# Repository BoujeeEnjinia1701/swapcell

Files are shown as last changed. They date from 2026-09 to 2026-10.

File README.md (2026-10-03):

# SwapCell

     

**Area:** Mobility and Logistics · **TRL:** 3 of 9 (proof of concept on paper) · **Value-engineering target:** about $700 USD · **Difficulty:** 4 of 5

Open-standard swappable battery pack and wall dock for e-bikes, scooters and cargo trikes, with a defined connector, CAN-based BMS protocol and state-of-health logging.

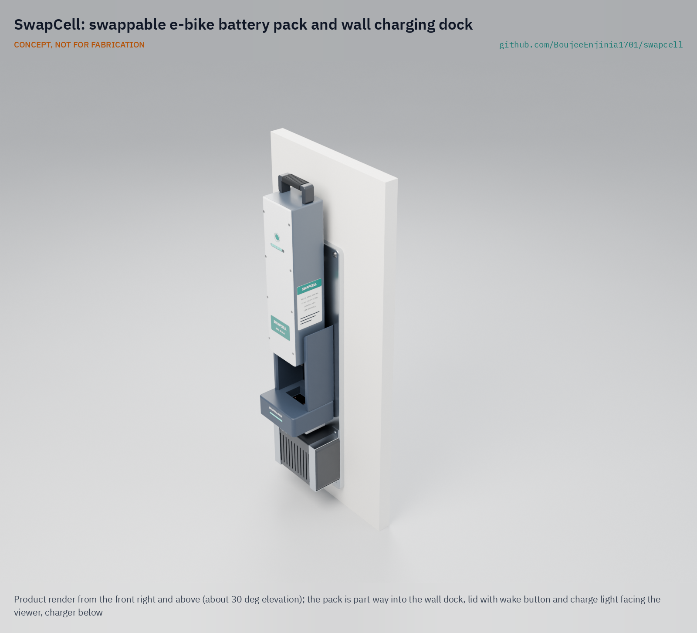
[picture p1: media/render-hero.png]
SwapCell: swappable e-bike battery pack and wall charging dock, product render


[Exploded render](media/render-exploded.png) · [Detail render](media/render-detail.png) · [Interactive 3D model](media/viewer.html) · [Concept blueprint (PDF)](media/concept-blueprint.pdf) · [Prototype build plan](docs/05-build-plan.md) · [Design decisions](docs/06-design-decisions.md) · [Review note](docs/REVIEW.md)

## Concept rationale

The cells inside almost every e-bike, scooter and cargo-trike battery are the same commodity 18650 or 21700 cells; what locks a pack to one brand is its housing, connector and data protocol. SwapCell therefore puts the effort into a published interface (envelope, pinout, coded interlock and CAN message set) rather than into a better cell. Once the interface is open, any fleet, workshop or small builder can make a pack or a receiver that works with everyone else's, and the pack's state-of-health log travels with it instead of living in a brand's cloud.

The reference build uses parts a garage workshop can source and assemble: commodity cells, an open-source BMS, a folded aluminium tray, a flame-retardant sheet lid and a certified off-the-shelf charger, so no custom mains electronics are needed. Keeping it open and buildable is what lets repair shops read and fix packs, and lets other open designs in this portfolio design around one battery instead of each inventing their own.

## Burning platform

Light electric vehicles are already the most electrified part of road transport: the IEA reports that about 8 % of the world's two- and three-wheelers were electric in 2023 and that electric models took 13 % of sales that year ([IEA, Global EV Outlook 2024](https://www.iea.org/reports/global-ev-outlook-2024/trends-in-other-light-duty-electric-vehicles)). In India, two-wheelers account for 70 to 80 % of all private vehicles ([NITI Aayog, draft Battery Swapping Policy, 2022](https://www.niti.gov.in/sites/default/files/2022-04/20220420_Battery_Swapping_Policy_Draft.pdf)), so how their batteries are charged, swapped and retired matters at national scale.

Closed, mismatched batteries are also a safety problem. In New York City, lithium-ion batteries caused 268 fires in 2023, killing 18 people and injuring 150 ([City of New York, 2024](https://www.nyc.gov/mayors-office/news/2024/07/mayor-adams-takes-new-actions-prevent-deadly-lithium-ion-battery-fires-promote-safe-e-bike)). A documented interface with a protected, dead-until-seated output and readable health data is one way to make safe, shared packs the easy choice.

## Where it could be used

### By industry

| Industry | Use |
| --- | --- |
| Last-mile delivery | Riders swap a flat pack for a charged one at a depot dock in seconds instead of waiting hours to charge |
| Bike and scooter sharing | One pack and dock family across mixed vehicle types, with state-of-health data to retire packs on evidence |
| Municipal, campus and industrial fleets | Shared packs for maintenance e-bikes, cargo trikes and site vehicles |
| Independent repair and refurbishment | Read a pack's log, find a weak cell group, repair it and return it to service |
| Agriculture and rural transport | Cargo trikes and e-bikes charged from a shared village dock or a small solar system |
| Off-grid energy | Retired or spare packs reused as storage in open power products such as PowerBox |

### By country or region

| Country or region | Why it matters there |
| --- | --- |
| India | About 880,000 electric two-wheelers and over 580,000 electric three-wheelers were sold in 2023 ([IEA](https://www.iea.org/reports/global-ev-outlook-2024/trends-in-other-light-duty-electric-vehicles)), and the government has proposed a battery swapping policy for these segments ([NITI Aayog](https://www.niti.gov.in/sites/default/files/2022-04/20220420_Battery_Swapping_Policy_Draft.pdf)) |
| China | Nearly 6 million electric two-wheelers were sold in 2023, the largest market in the world ([IEA](https://www.iea.org/reports/global-ev-outlook-2024/trends-in-other-light-duty-electric-vehicles)) |
| Kenya | Newly registered motorcycles, many used as boda-boda taxis, were estimated at 1.5 million in 2018 and could pass 5 million by 2030 ([UNEP](https://www.unep.org/news-and-stories/story/kenya-gets-breather-courtesy-electric-motorcycles)) |
| Viet Nam and Southeast Asia | Electric two-wheeler sales in Viet Nam were about 250,000 in 2023, and the electric share across ASEAN was only about 3 % ([IEA](https://www.iea.org/reports/global-ev-outlook-2024/trends-in-other-light-duty-electric-vehicles)), so shared packs could lower the entry cost |
| United States (New York City) | 268 lithium-ion battery fires and 18 deaths in 2023, and a city pilot of public battery charging for delivery workers ([City of New York](https://www.nyc.gov/mayors-office/news/2024/07/mayor-adams-takes-new-actions-prevent-deadly-lithium-ion-battery-fires-promote-safe-e-bike)) |

## What sparked the idea

The starting point was India's draft Battery Swapping Policy, published by NITI Aayog in April 2022 ([PDF](https://www.niti.gov.in/sites/default/files/2022-04/20220420_Battery_Swapping_Policy_Draft.pdf)). It asks for swappable batteries for two- and three-wheelers to be BMS-enabled, calls for standards for cables, connectors and repeated coupling tests, and favors open communication protocols so that batteries, vehicles and stations from different makers can work together. Those are the pieces of a common pack that no single brand has an incentive to publish. SwapCell takes that list literally and writes the interface down in the open: envelope, connector pinout with a coded interlock, CAN message set and health log, sized for e-bikes and cargo trikes.

## Problem

Every light electric vehicle brand uses its own battery, so fleets cannot share packs or chargers and batteries are scrapped early.

## Concept

Open-standard swappable battery pack and wall dock for e-bikes, scooters and cargo trikes, with a defined connector, CAN-based BMS protocol and state-of-health logging.

The core deliverable is the open **SwapCell interface v0.4**: envelope, blind-mate pinout with a coded interlock, CAN message set with a full bit layout, wake for hosts without CAN, a charge-while-discharging mode and a vehicle latch rating with its catch geometry published. Other portfolio designs build to it.

Full design precis: [docs/02-concept.md](docs/02-concept.md) · Sizing note: [docs/04-calcs/01-sizing.md](docs/04-calcs/01-sizing.md) · General arrangement: [cad/drawings/SWC-DWG-002.pdf](cad/drawings/SWC-DWG-002.pdf)

## Key components

- 26 x 21700 cells in 13S2P: 46.8 V, 10 Ah, about 468 Wh; pack about 3.0 kg
- Open-source BMS with CAN
- Folded aluminium tray with a flame-retardant UL 94 V-0 lid (polycarbonate sheet on the prototype)
- Blind-mate power and signal connector with a coded interlock
- Certified 5 A dock charger
- Latch pawl rated for vehicle class V1
- ESP32 dock controller

The priced bill of materials is in [bom/bom.csv](bom/bom.csv). Value-engineering target: USD 700. Estimated cost of the constructable design: USD 619 for one pack and one dock (USD 81 under the target).

## Building the prototype

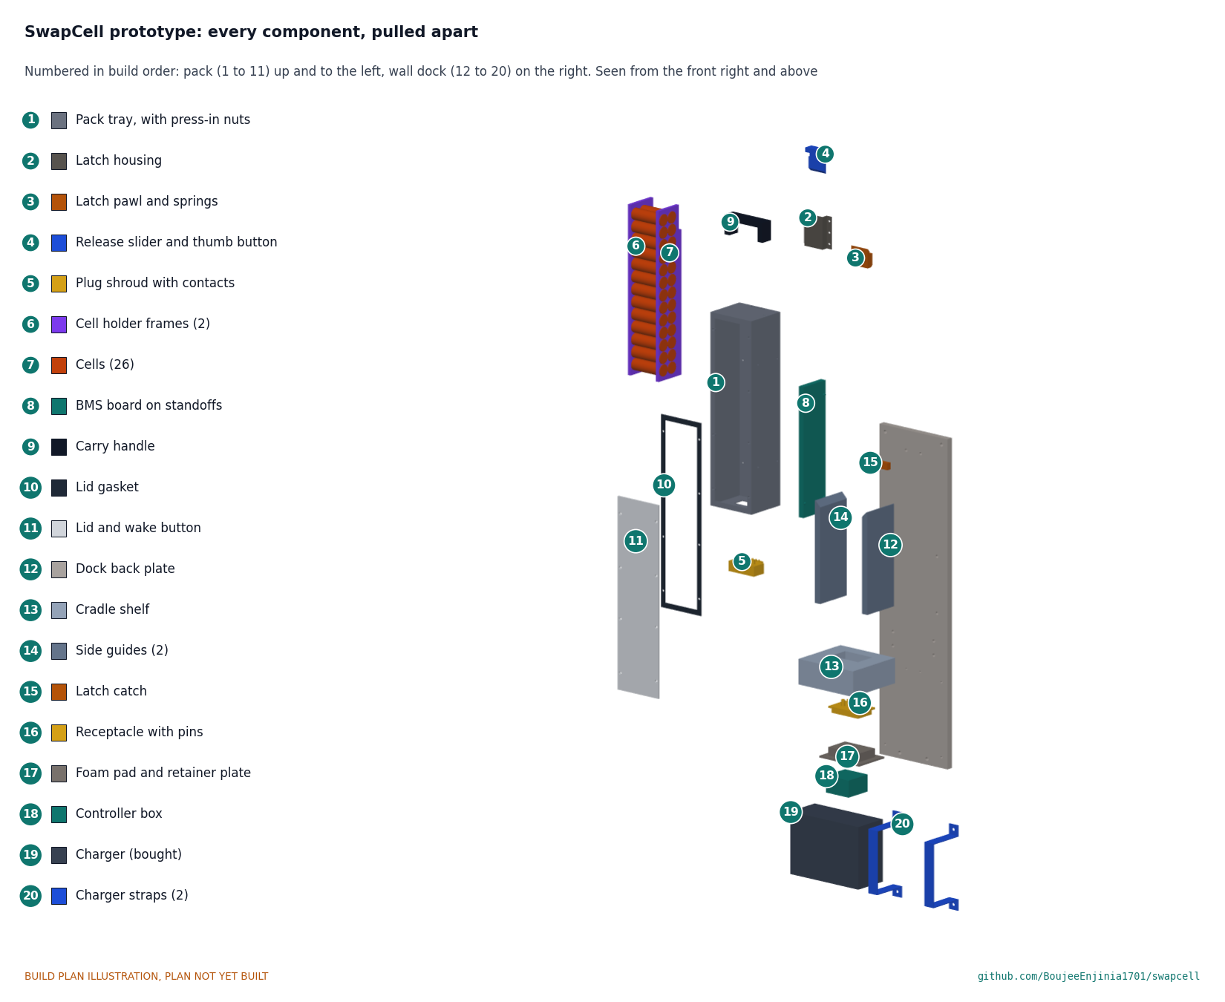
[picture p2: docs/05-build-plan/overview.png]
SwapCell prototype: every component pulled apart and numbered in build order


The [prototype build plan](docs/05-build-plan.md) (SWC-BLD-001) shows, in pictures, how to make each of the twenty components of one pack and one wall dock and put them together in seventeen steps; nothing has been built yet. The made parts are a folded aluminium tray, a steel latch with a thumb release, printed plug, receptacle, cell frames, handle, shelf and guides, and a 12 mm aluminium back plate; the cells, battery management board, contacts, charger and controller are bought. Writing the plan made the design buildable: the latch was redesigned so it actually holds the pack, the receptacle now floats, and every part has a fixing (SWC-DDR-003, open for Amish's review). Every picture is drawn from the model, which checks that each part touches what it should and clears what it should not; open questions are in the [design decisions register](docs/06-design-decisions.md).

## Safety

> Contains a 468 Wh lithium-ion battery pack at up to 54.6 V DC. Use a BMS with cell-level protection, fuse the pack, and charge on a non-combustible surface. Build and test packs only inside a fireproof enclosure, never unattended. This is a paper design at TRL 3; nothing here is certified.

## Repository layout

| Folder | Contents |
| --- | --- |
| `docs/` | Problem, concept, requirements, calculations and design decisions |
| `cad/src/` | build123d Python source, the source of truth for all geometry |
| `cad/step/`, `cad/stl/` | Exported models for FreeCAD, other CAD tools and printing |
| `cad/drawings/` | 2D sketches and dimensioned drawings |
| `bom/` | Bill of materials |
| `electronics/` | KiCad schematics and PCB layouts |
| `firmware/` | Microcontroller code |
| `media/` | Renders, perspectives and photos |
| `build-log/` | Dated prototyping notes |

## Documentation

Controlled documents follow the portfolio [documentation standard](.kit/STANDARDS.md). Each carries a document ID (SWC-PRC-001 for the precis), a version and a revision history. Branded PDFs are built with `python .kit/render.py` and attached to GitHub Releases when a document is tagged, for example `SWC-PRC-001/v1.0`.

## Credits

Designed by Amish Chadha. See [CONTRIBUTORS.md](CONTRIBUTORS.md) for roles. To cite this design, use [CITATION.cff](CITATION.cff) (GitHub shows it as "Cite this repository").

AI assistance (Claude) was used to accelerate concept renders, prototype documentation and first-pass sizing calculations. Design direction and all decisions are Amish Chadha's, recorded in this repository's decision records (`docs/decisions/`).

## Licenses

- **Hardware** (CAD, drawings, BOM, electronics): [CERN-OHL-S v2](LICENSE)
- **Software** (firmware, scripts, notebooks): [MIT](LICENSE-SOFTWARE)

A project of the [Design Molecule](https://designmolecule.com) lab.

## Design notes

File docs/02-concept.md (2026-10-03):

---
doc_id: SWC-PRC-001
title: SwapCell design precis
project: SwapCell
doc_type: Design precis
version: "0.7"
status: Draft
date: '2026-10-02'
author: Amish Chadha
license: CERN-OHL-S-2.0
revisions:
- version: "0.1"
  date: '2026-09-24'
  author: Amish Chadha
  change: Initial scaffold
- version: "0.2"
  date: '2026-09-24'
  author: Amish Chadha
  change: Populate to TRL 2 (architecture, interface definition, first-order numbers, safety, media)
- version: "0.3"
  date: '2026-09-25'
  author: Amish Chadha
  change: TRL 3. Issue SwapCell interface v0.3 (wake item W, charge-discharge item C, latch class V1 item V, full CAN bit layout); record Amish's decisions (SWC-DDR-001); numbers checked against SWC-CAL-001
- version: "0.4"
  date: '2026-09-25'
  author: Amish Chadha
  change: Recommendations accepted by Amish (DDR-002)
- version: "0.5"
  date: '2026-10-01'
  author: Amish Chadha
  change: Constructable design (SWC-DDR-003) latch, fixings and dock; mass and cost updated; budget treated as a value-engineering target
- version: "0.6"
  date: '2026-10-02'
  author: Amish Chadha
  change: "Issue SwapCell interface v0.4 (handle zone 84 x 43 mm, catch geometry, reserved LFP chemistry code and coding key); polycarbonate sheet lid for the prototype; partner, LFP and EnergyBus decisions of 2026-10-02"
- version: "0.7"
  date: '2026-10-02'
  author: Amish Chadha
  change: "Approved follow-ups carried out: lid line repriced for polycarbonate sheet (cost USD 619); board temperature sensor on the rear row of cells modelled; GA SWC-DWG-002 Rev P4 shows the handle zone and catch geometry"
---

# SwapCell design precis

SwapCell is a 48 V, 10 Ah lithium-ion pack of 26 cells in a 340 x 90 x 80 mm body that drops, connector first, into a wall dock or a vehicle mount, mates through a floating blind-mate connector, and talks to whatever it is plugged into over CAN. The pack carries its own state-of-health log, so any dock can read its history. The sizing note SWC-CAL-001 confirms that the 13S2P pack of 21700 cells gives about 468 Wh at about 3.0 kg, charges in about 2.3 h on a 5 A dock, and costs about USD 449 in prototype parts, with the dock adding about USD 170. The design was made constructable on 2026-10-01 (SWC-DDR-003, open for Amish's review), and the prototype build plan SWC-BLD-001 shows how it is made. Cycle life (R9) remains at risk. Cell temperature at 20 A (R3) is handled by the temperature derating rule Amish chose on 2026-09-25 (SWC-DDR-002).

The interface (envelope, pinout and message set) is the core deliverable of this precis. This version issues **SwapCell interface v0.4**, which widens the handle zone and publishes the latch catch geometry (Amish, 2026-10-02), on top of v0.3, which added three items Amish approved on 2026-09-25: a wake method for hosts without CAN or a wake supply (item W), a charge-while-discharging mode (item C) and a latch vibration rating for vehicles (item V). PowerBox, SunSpoke, StepGen, WaterWalker, CargoMule, FieldCell and other designs build to it.

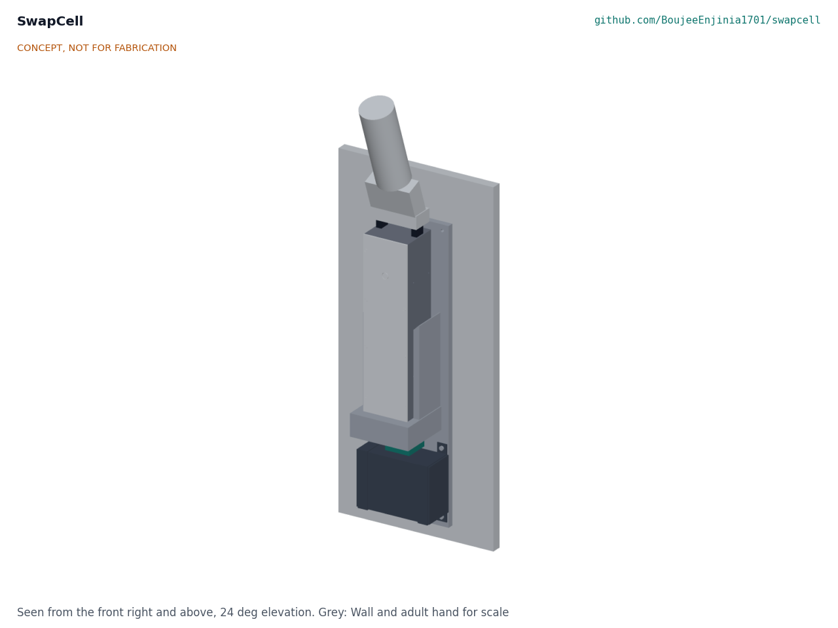
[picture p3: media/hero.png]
Hero render


*Figure 1. Pack seated in the wall dock, with a hand on the carry handle for scale. Rendered from the parametric model `cad/src/model.py`.*

## How it works

1. **Dock.** The pack hangs connector end down in a wall cradle. Side guides bring it within the connector's capture range, gravity seats it, and a spring-loaded pawl on the back face snaps out under a catch on the cradle.
2. **Mate and wake.** The blind-mate connector makes contact in sequence: ground first, then power and CAN, and a short interlock pin last. The receiver's 10 kΩ coding resistor in the INTERLOCK loop wakes a sleeping pack without any supply from the host. Until the pack has checked that loop, the output is dead.
3. **Handshake.** The dock controller (ESP32 with a CAN transceiver) sends a heartbeat. The pack answers with its identity, limits and state of health. If the pack reports no fault and a charge limit of at least 5 A, the dock switches its certified 54.6 V, 5 A charger onto the pack.
4. **Charge and log.** The BMS balances cells, limits charge by temperature and records each cycle. The dock copies new cycle records to its SD card and exports them as CSV.
5. **Swap.** The rider lifts the pack by the handle, releases the latch with the same hand, and slides it into the vehicle mount, which mirrors the dock cradle and closes an over-centre lever to hold the pack against vibration (latch class V1). The vehicle controller runs the same handshake, and the pack enables its output. A vehicle without CAN gets legacy discharge-only output at 15 A.
6. **Charge while in use.** A station host such as PowerBox, or a vehicle that recovers energy, requests the charge-discharge mode and may push current into the pack while drawing from it, within the limits the pack publishes.

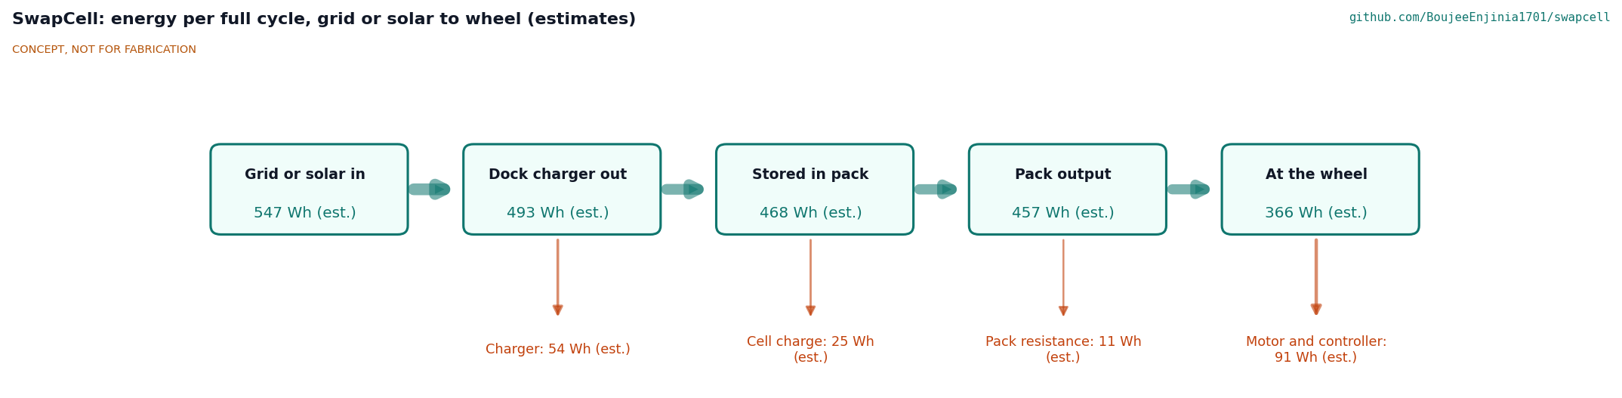
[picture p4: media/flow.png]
System and energy flow


*Figure 2. Energy per full charge and discharge, grid or solar to wheel. All values are estimates from SWC-CAL-001.*

## Main components

| # | Component | Proposed choice | Notes |
| --- | --- | --- | --- |
| 1 | Pack housing tray | Folded 1.5 mm 5052 aluminium, open front, flame-retardant liner, riveted latch doubler | Carries the latch and handle loads; spreads heat. Decided by Amish, 2026-09-25 |
| 2 | Cell block | 26 x 21700 cells, 13S2P, 5.0 Ah nominal (4.85 Ah minimum) and 3.6 V each, 25 A continuous rating | Cells in holders with fuse-wire links. Decided by Amish, 2026-09-25 |
| 3 | BMS board | Open-source 13S BMS with CAN, balancing, 30 A continuous FETs, pre-charge, flash log, 100 µA sleep with INTERLOCK wake | Stands beside the cells on its long edge |
| 4 | Pack lid | Flame-retardant polymer (UL 94 V-0 grade) on a flat gasket, eight countersunk screws into press-in nuts in the tray's front flanges, flush sealed wake button | Removable for repair |
| 5 | Blind-mate plug, pack side | 2 power contacts (40 A) plus 6 potted signal contacts in a keyed shroud | Fixed to the pack; custom keyed shroud with commercial contacts, decided 2026-09-25 (SWC-DDR-002) |
| 6 | Carry handle | Printed or moulded loop over the top end, 25 mm grip clearance, two screws from inside | Sized for a gloved hand |
| 7 | Latch pawl | Steel pawl sliding through the back wall in a riveted steel housing (the doubler), 6 mm proud, hooking 4 mm under the catch; a thumb button just behind the grip drives a ramped slider that pulls it in 5 mm; 1.72 kN proof load | Same catch geometry on dock and vehicle (SWC-DDR-003) |
| 8 | Wall dock cradle | 12 mm aluminium back plate, printed cradle shelf with connector pocket, printed side guides with lead-ins and a steel latch catch, each screwed from behind the plate | Wall-mounted at 0.8 to 1.2 m |
| 9 | Blind-mate receptacle, dock side | Mating half captured under the shelf pocket on a foam pad, floating ±3 mm and ±2°, 10 kΩ INTERLOCK coding resistor | Replaceable wear part |
| 10 | Dock charger | Certified 54.6 V, 5 A CC-CV lithium-ion charger, settable to 53.3 V for fleet mode | Off-the-shelf; no custom mains electronics. Decided by Amish, 2026-09-25 |
| 11 | Dock controller | ESP32 with CAN transceiver, charger relay, current sensor and SD card | Runs the handshake and exports logs |

Item 12 (fuses, pre-charge and wiring) is in the BOM but not modelled, apart from the battery board's temperature sensor on the rear row of cells; the label of item 14 is not modelled; items 13 (seals and fixings), 15 (latch housing and release), 16 (cell holder frames) and 17 (dock mounting parts) are modelled and shown in the build plan. Numbers match `bom/bom.csv` and Figure 4. The general arrangement is drawing SWC-DWG-002 (`cad/drawings/SWC-DWG-002.pdf`), generated from `cad/src/model.py`.

## Key numbers

All values come from SWC-CAL-001 (`docs/04-calcs/sizing.py`) and are paper estimates. Cell assumptions: 5.0 Ah nominal and 4.85 Ah minimum, 3.6 V nominal, 3.0 to 4.2 V, about 69 g, about 12 mΩ DC internal resistance, 25 A continuous, about $5.50 in small quantity.

| Quantity | Value | Basis | Requirement |
| --- | --- | --- | --- |
| Configuration | 13S2P, 26 cells | Decided by Amish, 2026-09-25 | |
| Voltage | 46.8 V nominal, 39.0 to 54.6 V | 13 x 3.6 V; 13 x 3.0 to 4.2 V | R1 met |
| Capacity and energy | 10.0 Ah and about 466 Wh at 0.2C; 9.7 Ah and 452 Wh at cell minimum | 2 x 5.0 Ah less sag | R2 **at risk** at cell minimum |
| Pack resistance | about 110 mΩ | 13 groups x 6 mΩ, plus 32 mΩ for links, fuse wires, FETs, shunt and connector | |
| Cell current | 10 A continuous, 17.5 A peak | 20 A and 35 A over 2 cells; rated 25 A | R3 electrically met |
| Cell hot spot, 20 A full discharge | about 51 °C in open air, 63 °C enclosed, 71 °C from 45 °C ambient | Lumped model, UA 1.17 W/K, τ 33 min | R3 met on paper with derating (SWC-DDR-002) |
| Heat at 10 A (typical e-bike) | about 11 W | I²R | |
| Voltage sag | about 2.2 V at 20 A, 3.9 V at 35 A | I x 110 mΩ | |
| Mass | about 3.03 kg (6.7 lb) | Cells 1.79 kg, tray 0.43, lid 0.11, interconnects 0.18, BMS 0.12, plug 0.06, handle and pawl 0.13, latch housing and release 0.11, seals, fixings and button 0.10 | R5 met |
| Body and overall size | 340 x 90 x 80 mm; 393 mm with handle and plug | Parametric model | R6 met |
| Energy density | about 154 Wh/kg, about 191 Wh/L | 468 Wh over 3.03 kg and 2.45 L | |
| Charge time at 5 A | about 2.3 h to full; 1.6 h to 80 %; 1.2 h for 20 to 80 % | CC to 85 % in 1.7 h, then about 0.6 h CV | R4 met |
| Dock input power | about 303 W in CC | 54.6 V x 5 A at 90 % | |
| Energy per cycle | about 547 Wh from grid or solar, about 457 Wh at the pack terminals | Figure 2 | |
| Range | about 38 to 57 km (e-bike), 18 to 30 km (loaded cargo trike) | 457 Wh at 12 to 8 Wh/km and 25 to 15 Wh/km | |
| Cell cost | about $143, $0.31/Wh | 26 x $5.50 | |
| Parts cost | about USD 449 per pack, USD 170 per dock, USD 619 total | `bom/bom.csv` | R16: USD 81 under the USD 700 value-engineering target |
| Cycle life | about 300 to 500 cycles to 80 % | Typical for the cell class; higher in 4.1 V fleet mode | R9 **at risk** |
| Sleep drain | about 0.72 % per month at 100 µA | Interface v0.3 item W | R13 met on paper |
| CAN bus load | about 1.8 % (one pack), 3.1 % (two packs) | 34.1 frames/s at 135 bits | R12 met on paper |

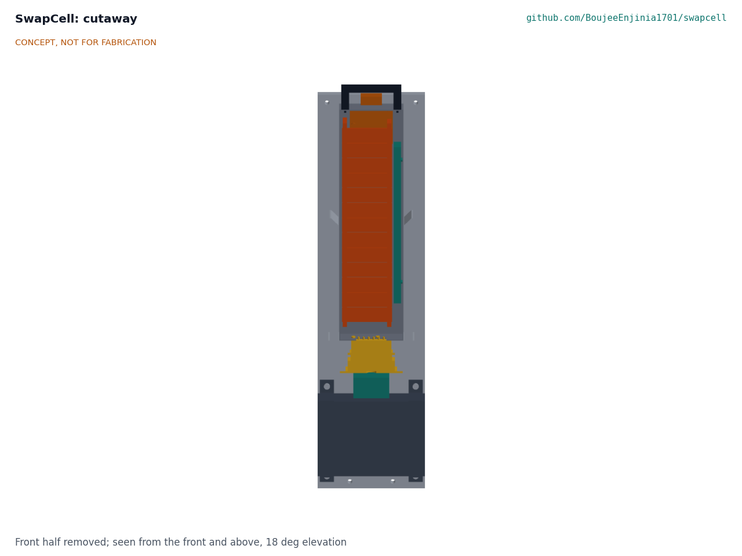
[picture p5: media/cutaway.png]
Cutaway


*Figure 3. Section through the docked pack: cells (2) with their axes across the width, BMS board (3) beside them, plug (5) in the dock receptacle (9).*

## Interface definition

This section is the **SwapCell interface, version 0.4** (draft, 2026-10-02). Amish approved v0.2 as written and the three v0.3 additions on 2026-09-25 (SWC-DDR-001), and the v0.4 changes of Table 1a on 2026-10-02 (SWC-DDR-003, A1 and A2; SWC-DEC-001). The specific values inside the additions (marked †) were engineering proposals; Amish confirmed them on 2026-09-25 (SWC-DDR-002). Other portfolio designs build to this section, cite it as "SwapCell interface v0.4", and flag any conflict to this repo rather than change it locally. Changes need Amish's approval.

*Table 1. Changes from v0.2.*

| Item | Change | Why | Requirement |
| --- | --- | --- | --- |
| W | Wake on a coded INTERLOCK loop (10 kΩ† to SGND in every receiver), plus a manual wake button; WAKE pin kept but optional | Battery-only and non-CAN hosts (PowerBox, legacy vehicles) have no wake supply | R13 |
| C | Requested mode 4, charge-discharge; host type 3, station; host charge limit in HOST_HEARTBEAT | PowerBox runs loads while charging from solar; vehicles may recover energy | R14 |
| V | Latch classes: D (gravity dock) and V1 (vehicle), with a proof load, preload and vibration profile | Vehicles shake; v0.2 had only a 3 g placeholder | R15 |
| L | Full CAN bit layout (Table 3) and interface version in PACK_STATUS | TRL 3 work listed in the TRL 2 review | R12 |

*Table 1a. Changes from v0.3 (2026-10-02).*

| Item | Change | Why | Requirement |
| --- | --- | --- | --- |
| H | Handle zone widened to 84 x 43 mm, from the zone's front edge to the back face | The thumb button sits behind the v0.3 zone; receivers must leave it clear | R6 |
| K | Catch geometry published: latching face 1 mm above the pawl, reach 8 mm from a plate 10 mm behind the pack, 4 mm engagement, 1 mm clear when retracted; pawl projection 6 mm, travel 5 mm | Every receiver must latch the same way | R15 |
| X | A chemistry code in the message set and a connector coding key are reserved for a 16S LFP variant, so an LFP pack can never take an NMC charge or the reverse; values and key geometry are assigned when an LFP variant is designed | Full charge differs (about 58.4 V for 16S LFP, 54.6 V for 13S NMC) | R12 |

### Mechanical envelope

| Feature | Value | Notes |
| --- | --- | --- |
| Body | 340 x 90 x 80 mm, +0 / -1.5 mm | Length along the insertion axis |
| Datum | Connector face (pack underside); insertion along the long axis, connector first | Same in dock and vehicle mount |
| Connector position | Centred across the 90 mm width, 8 mm toward the back face from the depth centre line | Keeps the plug clear of the lid seam |
| Guide faces | The two 340 x 80 mm side faces, 90 mm apart | Receiver guides with 1 mm clearance per side and a 10 mm lead-in |
| Latch | Pawl on the back face, 45 mm below the top end, 36 mm wide, 4 mm tooth, 6 mm projection, 5 mm travel; engages a catch on the receiver whose latching face is 1 mm above the pawl, reaching 8 mm from a plate 10 mm behind the pack, for 4 mm of engagement (v0.4) | Proof load 1.72 kN† along the insertion axis |
| Handle zone | Up to 35 mm above the top end, 84 x 43 mm footprint, from the zone's front edge to the back face (v0.4) | Receivers leave this zone clear, including the thumb button |
| Wake button | Flush in the lid (front) face, 12 mm, 70 mm below the top end | New in v0.3; inside the envelope |
| Orientation | Any; the latch, not gravity, retains the pack in a vehicle | Dock uses gravity to seat |
| Mass limit for receivers | 3.5 kg pack | R5 |
| Airflow | Vehicle receivers leave the back and lid faces open to air where possible | The full 20 A rating applies in an open-air mount; enclosed, the pack derates to about 18.6 A (R3) |

**Latch classes (item V).** *Class D* (gravity dock): the pack seats under its own weight; the latch only stops it being knocked out. *Class V1* (vehicle): the receiver and the pack latch together hold the pack with no latch release and no power-contact interruption of 1 ms or longer under the sinusoidal vibration profile of UN 38.3 test T3 (7 to 200 Hz, peak 8 g, three axes) and 25 g†, 11 ms half-sine shocks, three in each direction on each axis. The receiver preloads the pack against its end stop with at least 330 N† through an over-centre lever (ratio 6.6 or more, hand force 50 N or less), so the contacts do not chatter at 8 g; the lever has a detent so it cannot open under vibration. The pack latch withstands a static 1.72 kN proof load along the insertion axis without permanent set. Verification is by test at TRL 4, which is on hold.

### Connector pinout

Two power contacts and six signal contacts in a keyed shroud that only mates one way round. Mating order is set by contact length.

| Pin | Signal | Rating | Mates | Function |
| --- | --- | --- | --- | --- |
| P1 | PACK+ | 40 A continuous | 2nd | Pack positive, behind the BMS FETs; dead until enabled |
| P2 | PACK- | 40 A continuous | 1st | Pack negative |
| S1 | SGND | 1 A | 1st | Signal ground and CAN reference, joined to PACK- inside the pack |
| S2 | CAN_H | Signal | 2nd | CAN 2.0B, 250 kbit/s; 120 Ω termination in the host, not the pack |
| S3 | CAN_L | Signal | 2nd | As above |
| S4 | WAKE | 5 to 15 V, 10 mA | 2nd | Optional in v0.3. A host may drive it high to wake the BMS or hold it awake |
| S5 | AUX | 12 V, 1 A (reserved) | 2nd | Proposed low-power output for lights or a dock display; off by default |
| S6 | INTERLOCK | Signal, 3.3 V, 30 µA | 3rd (last) | **v0.3:** loops to SGND through a 10 kΩ† ±1 % coding resistor in every receiver. The pack accepts 8.0 to 12.5 kΩ (node 0.24 to 0.37 V); a short, an open loop or any other value keeps the output dead. It is also the wake source (item W) |

### Wake and sleep (item W)

In sleep the BMS draws 100 µA† or less and holds INTERLOCK at 3.3 V through 100 kΩ, with a comparator armed. The pack wakes on any of: INTERLOCK falling below 1.0 V, WAKE driven high, the manual button, or (optionally) CAN activity. Awake, it measures the INTERLOCK resistance. If the loop is valid, it goes to standby and waits for a heartbeat; if not, it sets a warning, keeps the output dead and sleeps again after 60 s, re-arming only when the node returns high, so a coin or water across the contacts cannot hold it awake. With no heartbeat, no current and a valid loop, the pack sleeps after 10 min unless a host holds WAKE high or sets the keep-awake flag. A host without CAN (legacy mode) therefore needs nothing but the coding resistor.

### CAN message set

CAN 2.0B controllers at 250 kbit/s, 11-bit identifiers. Each pack has a node number n from 0 to 7 (default 0) so a vehicle can carry two packs; identifiers below are base values plus n. All signals are little-endian unsigned integers unless marked signed. Current is positive out of the pack.

*Table 2. Messages.*

| ID (base) | Message | Direction | Rate |
| --- | --- | --- | --- |
| 0x100 | PACK_STATUS | Pack to host | 10 Hz |
| 0x110 | PACK_LIMITS | Pack to host | 10 Hz |
| 0x120 | CELL_SUMMARY | Pack to host | 1 Hz |
| 0x130 | TEMPERATURES | Pack to host | 1 Hz |
| 0x140 | FAULTS | Pack to host | On change and 1 Hz |
| 0x150 | STATE_OF_HEALTH | Pack to host | 0.1 Hz |
| 0x160 | IDENTITY | Pack to host | On request (remote frame or HOST_HEARTBEAT flag) |
| 0x180 | HOST_HEARTBEAT | Host to pack | 10 Hz |
| 0x190 | CHARGER_STATUS | Dock or station to pack | 1 Hz |
| 0x1F0 / 0x1F8 | LOG_REQUEST / LOG_DATA | Dock to pack / pack to dock | On request; segmented transfer in the style of ISO 15765-2 |

*Table 3. Bit layout (8 data bytes per frame; byte 0 first).*

| Message | Bytes | Signal | Scale and range |
| --- | --- | --- | --- |
| PACK_STATUS | 0 to 1 | Pack voltage | 10 mV, 0 to 655.35 V |
| | 2 to 3 | Pack current, signed | 100 mA, ±3,276.7 A |
| | 4 | State of charge | 0.5 %, 0 to 100 % |
| | 5 | State | 0 sleep, 1 standby, 2 discharge, 3 charge, 4 charge-discharge, 5 legacy discharge, 6 fault |
| | 6 | Flags | bit 0 INTERLOCK valid, 1 heartbeat valid, 2 discharge FET on, 3 charge FET on, 4 pre-charge active, 5 to 6 wake source (0 INTERLOCK, 1 WAKE, 2 button, 3 CAN), 7 fleet mode |
| | 7 | Counter and version | bits 0 to 3 rolling counter, bits 4 to 7 interface minor version (4 for v0.4) |
| PACK_LIMITS | 0 to 1 | Allowed discharge current | 0.1 A |
| | 2 to 3 | Allowed charge current | 0.1 A; 0 below 0 °C and above 45 °C cell temperature |
| | 4 to 5 | Maximum charge voltage | 10 mV (54.60 V standard, 53.30 V fleet) |
| | 6 to 7 | Minimum pack voltage | 10 mV |
| CELL_SUMMARY | 0 to 1, 2 | Minimum cell voltage, group index | 1 mV; 0 to 12 |
| | 3 to 4, 5 | Maximum cell voltage, group index | 1 mV; 0 to 12 |
| | 6 to 7 | Imbalance | 1 mV |
| TEMPERATURES | 0, 1 | Minimum and maximum cell temperature, signed | 1 °C |
| | 2, 3 | FET and connector temperature, signed | 1 °C |
| | 4, 5 | Sensor index of minimum and maximum | 0 to 255 |
| | 6 to 7 | Reserved | 0 |
| FAULTS | 0 to 3 | Fault bits | 0 cell overvoltage, 1 cell undervoltage, 2 discharge overcurrent, 3 charge overcurrent, 4 short circuit, 5 over-temperature, 6 under-temperature charge, 7 INTERLOCK invalid, 8 heartbeat lost, 9 pre-charge failed, 10 FET failure, 11 cell imbalance, 12 isolation or water ingress, 13 to 31 reserved |
| | 4 to 5 | Warning bits | Same order as faults, early warning thresholds |
| | 6 | Seconds until disconnect | 1 s; 255 = none pending |
| | 7 | Rolling counter | 0 to 255 |
| STATE_OF_HEALTH | 0 | SoH | 0.5 % |
| | 1 to 2 | Full-charge capacity | 10 mAh |
| | 3 to 4 | Cycle count | 1 |
| | 5 to 6 | Lifetime throughput | 10 Ah |
| | 7 | Resistance estimate | 1 mΩ, 0 to 255 |
| IDENTITY | 0 | Page | 0 to 3 |
| | 1 to 7 | Page 0: interface major and minor, chemistry code, series count, parallel count, rated capacity (0.1 Ah, 2 bytes); pages 1 and 2: serial number (14 ASCII bytes); page 3: firmware version | |
| HOST_HEARTBEAT | 0 | Host type | 0 vehicle, 1 dock, 2 tester, 3 station (new in v0.3) |
| | 1 | Requested mode | 0 sleep, 1 standby, 2 discharge, 3 charge, 4 charge-discharge (new in v0.3) |
| | 2 to 3 | Host discharge current limit | 0.1 A |
| | 4 to 5 | Host charge current limit | 0.1 A (new in v0.3) |
| | 6 | Flags | bit 0 fleet mode, 1 keep awake, 2 request IDENTITY, 3 to 7 reserved |
| | 7 | Rolling counter | 0 to 255 |
| CHARGER_STATUS | 0 to 1, 2 to 3 | Charger voltage and current capability | 10 mV, 0.1 A |
| | 4 to 5, 6 to 7 | Measured output voltage and current | 10 mV, 0.1 A |

### Behavior rules

- **Enable.** The pack enables any output only with a valid INTERLOCK loop. Discharge needs a heartbeat requesting mode 2 or 4; charge needs a heartbeat from a dock, station or vehicle requesting mode 3 or 4. A heartbeat is valid while its counter advances at least every 300 ms.
- **Legacy mode (decided).** If INTERLOCK is valid and no heartbeat arrives within 2 s, the pack enables discharge only, limited to 15 A, and never charges or enters mode 4.
- **Charge-discharge mode (item C).** In mode 4 both FETs are on and current may flow either way. The host keeps net charge current at or below the lower of its own charge limit and the pack's allowed charge current, and the pack terminal voltage at or below the maximum charge voltage. The pack enforces its limits: on a charge-side fault (charge overcurrent, a cell near overvoltage, or cell temperature below 0 °C or above 45 °C) it sets allowed charge current to zero, warns, and after 1 s opens only the charge FET, so discharge continues through that FET's body diode and the load stays powered. Mode changes between 2, 3 and 4 never open the output.
- **Temperature derating (R3, decided 2026-09-25).** PACK_LIMITS allows the full 20 A continuous discharge while the hottest cell is at or below 50 °C, then lowers the allowed discharge current linearly to 5 A at 60 °C. The 35 A, 10 s peak is allowed only below 50 °C. Hosts must follow PACK_LIMITS; a legacy host is already held to 15 A and gets the same ramp. The pack sustains about 18.6 A in an enclosed mount from 25 °C and about 14 A in open air from 45 °C (SWC-CAL-001 v0.2).
- **Warn, then derate.** For a non-fatal fault the pack first warns and ramps its current limit down over about 5 s, so a rider is not left without power mid-junction. It opens immediately only for short circuit, cell overvoltage or over-temperature beyond the hard limit.
- **Removal.** When INTERLOCK opens (it breaks first on removal), the pack opens its output within 1 ms, before the power contacts separate.

**State-of-health log.** One 32-byte record per charge or discharge event: dock timestamp, Ah in and out, minimum and maximum temperature, peak current, minimum cell voltage, capacity and resistance estimates. 2,000 records need 64,000 bytes, which fits in the BMS microcontroller flash or a small SPI flash and transfers in about 10 s (R12).

**EnergyBus gateway.** Decided: an open SwapCell profile now, with a gateway study. The study is not complete. A gateway (an ESP32 translating between the two message sets) looks feasible in principle, since both carry voltage, current, limits and state, but a message-by-message mapping needs the CiA 454 specification, which is distributed through a membership organization and was not read for this version.

## Key design choices

All of these were decided by Amish on 2026-09-25 (go with recommendation), SWC-DDR-001, unless marked otherwise.

- **13S2P of 5 Ah 21700 cells.** Meets 10 Ah with 26 cells and 52 welds. A 13S4P "double" pack (about 900 Wh, about 5 kg) is a later variant in a longer envelope.
- **Aluminium tray with a flame-retardant lid (3 mm UL 94 V-0 polycarbonate sheet for the prototype, decided 2026-10-02; a printed V-0 lid remains allowed).** Metal spreads heat, resists a cell fire longer than a printed shell and carries the 1.72 kN latch proof load through a riveted doubler.
- **Floating blind-mate connector with a dead pack output and a coded interlock.** Sequenced contacts and a last-mate, resistor-coded interlock keep the output off until the pack is seated in a real receiver, avoid arcing on insertion and let a receiver wake the pack.
- **Own open message set, with an EnergyBus gateway study.** Short, published and easy to implement on an ESP32 or a hobby controller.
- **Legacy mode for vehicles without CAN.** Discharge only, fixed at 15 A.
- **The log lives in the pack.** Any dock, anywhere, can read a pack's history without a shared server.
- **Certified charger, switched by the dock.** The dock builds no mains electronics; charge current is fixed at 5 A.
- **Fleet charge mode.** The dock may set 4.1 V per cell (53.3 V) for longer life at about 10 % less energy.
- **Interface governance.** This section is the versioned interface; Amish approves changes.
- **Solar DC dock variant.** A second dock with a 48 V DC input (via PowerBox) follows the mains dock; not designed at TRL 3.
- **Connector family (decided 2026-09-25, SWC-DDR-002).** A custom printed keyed shroud around commercial high-current socket contacts and potted spring signal contacts, rather than a commercial blind-mate connector, because it keeps the published geometry independent of one vendor; the contacts are bought and replaceable. The specific contact parts are chosen at supplier selection. R8 and R10 depend on them and are verified at TRL 4, which is on hold.
- **R3 thermal rating (decided 2026-09-25, SWC-DDR-002).** Keep 20 A continuous at 25 °C with the temperature derating rule above, rather than labelling the pack 15 A.
- **Values inside items W, C and V (confirmed 2026-09-25, SWC-DDR-002).** 10 kΩ coded INTERLOCK, 100 µA sleep limit, 25 g shock, 330 N receiver preload, and the charge-FET fallback on a charge-side fault.

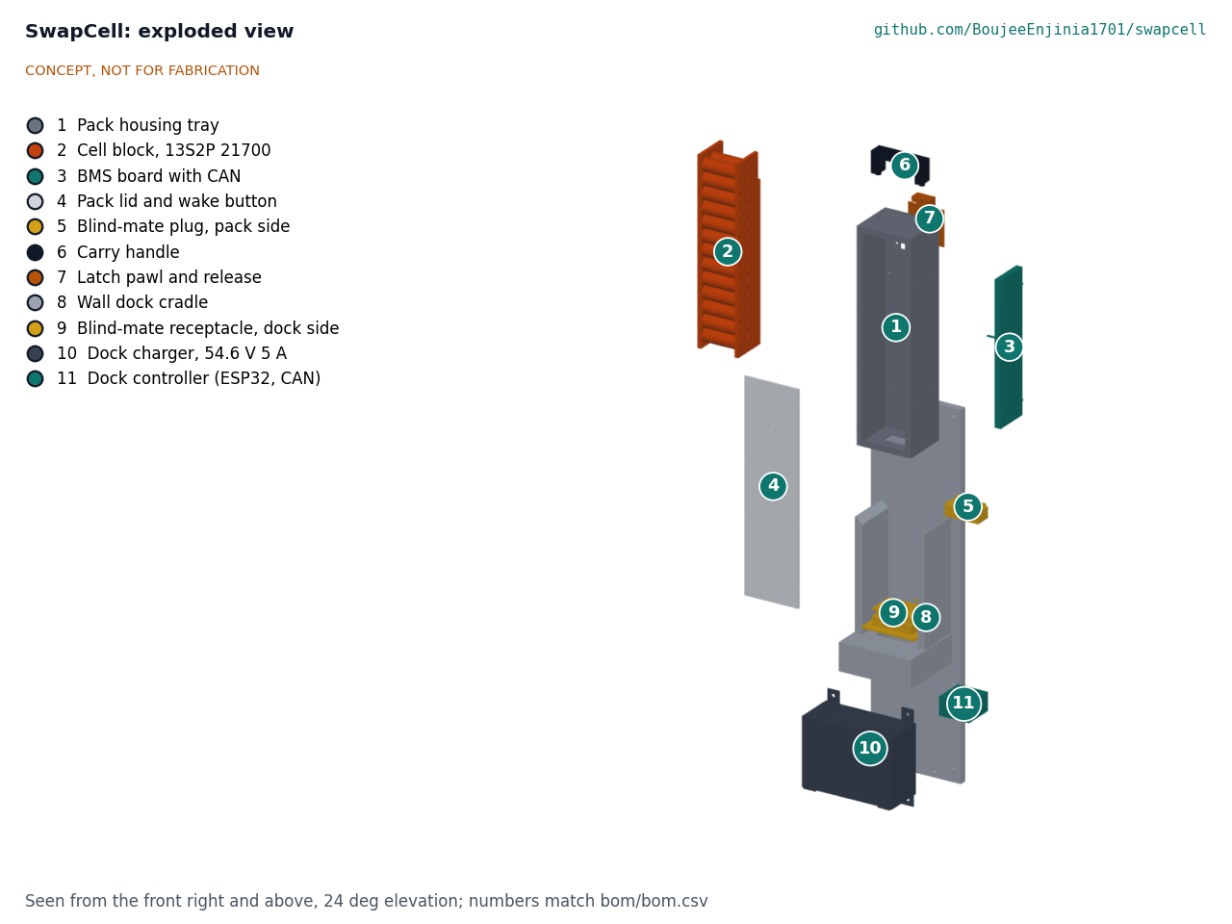
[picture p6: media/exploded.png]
Exploded view


*Figure 4. Exploded view with callouts numbered as in the components table and `bom/bom.csv`.*

## Safety

> **Safety:** SwapCell is a 468 Wh lithium-ion pack. A cell in thermal runaway vents flammable, toxic gas and can ignite its neighbours; a pack fire is hard to extinguish and can re-ignite hours later. Treat every pack as a fire hazard at all stages.

- **Thermal runaway.** Use new cells from a reputable distributor, with matched capacity and resistance. Space cells in holders (about 1 mm gaps) and consider a mica or intumescent barrier between groups; line the tray with a flame-retardant sheet; give the housing a vent path that directs gas away from the handle and the user. Propagation resistance was not analyzed at TRL 3 and can only be shown by test, which is TRL 4 work and on hold.
- **Cell-level fusing.** Each cell connects to its bus through a fuse wire or fusible link sized to carry 17.5 A peak without damage but to open on the fault current of an internally shorted neighbour. A 40 A main fuse sits in series with PACK+.
- **BMS protections (R11).** Cell overvoltage and undervoltage, charge and discharge overcurrent, short-circuit trip within 500 µs, over-temperature, no charging below 0 °C, pre-charge of the host's input capacitors, and an output that stays off until the interlock closes. Exposed pack contacts are at up to 54.6 V DC and can deliver hundreds of amperes into a short, so the dead-output rule is a safety requirement, not a convenience.
- **Coded interlock (v0.3).** A bare link or a coin across INTERLOCK and SGND reads as a short and never enables the output, even in legacy mode. Receivers must fit the 10 kΩ coding resistor; a receiver that shorts the loop simply does not work, which fails safe.
- **Charge-discharge mode (v0.3).** A host that pushes current into a pack is a charger. The pack refuses charge below 0 °C and above 45 °C and opens only its charge FET on a charge-side fault, so the load stays powered and the cells are protected. Hosts must still limit their own charge current and voltage.
- **Pack retention in vehicles (v0.3).** A pack that leaves its mount at speed is a 3 kg projectile with live contacts. Vehicle receivers must meet latch class V1, with an over-centre lever that cannot open under vibration.
- **Loss of power while riding.** A pack that cuts out suddenly can cause a fall. The warn-then-derate rule in the message set applies to every fault except the hard ones.
- **Dock location.** Mount docks on a non-combustible wall, away from exits and escape routes, with a smoke alarm nearby. Do not charge packs that have been dropped, crushed or wetted until they have been inspected.
- **Transport rules.** At about 468 Wh the pack is well above 100 Wh, so it ships as Class 9 dangerous goods (UN 3480 alone, UN 3481 in or with equipment), needs a UN 38.3 test summary before commercial shipping, cannot travel in passenger air baggage, and by air generally has to ship at 30 % state of charge or less. Moving prototype packs by road between workshops still needs terminal protection and a rigid, non-conductive container.
- **Building and testing.** Build, charge and test prototype packs only inside a fireproof enclosure (a steel cabinet or a purpose-made battery containment box) on a non-combustible surface, with a Class D or lithium-rated extinguisher and a sand bucket at hand, and never unattended. Use insulated tools, cover exposed bus bars, and build the pack one series group at a time with the BMS disconnected until wiring is checked.
- **Standards.** EN 50604-1 and UL 2271 (light-vehicle batteries), UL 2849 (e-bike electrical systems) and IEC 62133-2 are future compliance targets. Nothing here is certified.

## Open questions

Every open item, with options and recommendations, is tracked in the design decisions register SWC-DEC-001 ([06-design-decisions.md](06-design-decisions.md)); the list below is a summary.

Items that remain open after SWC-DDR-002. None of them is TRL 4 work to be started now; TRL 4 is on hold by Amish's instruction.

- **Cell model (R9).** Which 5 Ah 21700 cell balances cycle life against current rating needs datasheet review against named cells; R9 stays at risk until then.
- **LFP variant.** A 16S LFP pack (about 51 V nominal, up to 58.4 V) would be safer and longer lived but heavier. PACK_LIMITS already allows a different voltage window. Decided 2026-10-02: not added now; a chemistry code and a coding key are reserved in interface v0.4 so an LFP pack can never take an NMC charge or the reverse.
- **EnergyBus mapping.** Deferred (2026-10-02): the native SwapCell profile stays the reference; CiA 454 is read only when a partner needs EnergyBus.
- **First co-design partner.** Left open under the portfolio rule, but an urban cargo-bike or e-bike delivery fleet is approached first, with a repair workshop second (decided 2026-10-02). Nothing is agreed.
- **Build budget for a second pack.** Decided 2026-09-25 to settle it before any build (about USD 1,068 for two packs and one dock with the constructable design); on hold with TRL 4.

Concept media: [blueprint sheet](../media/concept-blueprint.pdf), [interactive 3D model](../media/viewer.html).

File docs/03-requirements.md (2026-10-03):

---
doc_id: SWC-REQ-001
title: SwapCell requirements
project: SwapCell
doc_type: Requirements
version: "0.7"
status: Draft
date: '2026-10-02'
author: Amish Chadha
license: CERN-OHL-S-2.0
revisions:
- version: "0.1"
  date: '2026-09-24'
  author: Amish Chadha
  change: Initial scaffold
- version: "0.2"
  date: '2026-09-24'
  author: Amish Chadha
  change: First measurable requirements for TRL 2 (electrical, mechanical, interface, protection)
- version: "0.3"
  date: '2026-09-25'
  author: Amish Chadha
  change: TRL 3. Record Amish's 2026-09-25 decisions (SWC-DDR-001); add R13 to R15 for interface v0.3 (wake, charge-discharge mode, latch class V1) and R16 budget scope; status from SWC-CAL-001
- version: "0.4"
  date: '2026-09-25'
  author: Amish Chadha
  change: Recommendations accepted by Amish (DDR-002)
- version: "0.5"
  date: '2026-10-01'
  author: Amish Chadha
  change: Constructable design (SWC-DDR-003) mass and cost; budget treated as a value-engineering target
- version: "0.6"
  date: '2026-10-02'
  author: Amish Chadha
  change: "Interface v0.4 noted (decisions of 2026-10-02); no requirement target or status changed"
- version: "0.7"
  date: '2026-10-02'
  author: Amish Chadha
  change: "R16 figures updated for the polycarbonate sheet lid (USD 619, USD 81 under the target); no requirement status changed"
---

# SwapCell requirements

These are the requirements for the pack, the dock and the SwapCell interface between them (v0.4 since 2026-10-02: handle zone 84 x 43 mm, catch geometry published, LFP chemistry code and coding key reserved; no requirement target changed). Amish accepted the TRL 2 recommendations on 2026-09-25 (SWC-DDR-001), including three interface additions, now R13 to R15. Requirements R6, R10 and R12 to R15 define the open interface that other portfolio designs depend on, so changes to them need Amish's approval. On 2026-09-25 Amish also accepted the remaining recommendations (SWC-DDR-002): R3 is restated around temperature derating, and the values inside R13 and R15 are confirmed. The status column comes from SWC-CAL-001 v0.2; no requirement is shown to be not met, and two are at risk.

| ID | Requirement | Target | Verification | Status (SWC-CAL-001) |
| --- | --- | --- | --- | --- |
| R1 | Nominal voltage in the 48 V light-vehicle class | 46.8 V nominal; operating window 39.0 to 54.6 V (3.0 to 4.2 V per cell) | Cell configuration calculation; datasheet | Met |
| R2 | Usable capacity and energy | 10 Ah or more and 450 Wh or more at 0.2C, 25 °C | Calculation from cell datasheet; later capacity test. Applies to the standard 4.2 V charge; fleet mode (4.1 V) gives about 419 Wh by design | At risk: 9.7 Ah at the cell datasheet minimum |
| R3 | Discharge current, continuous and peak, with temperature derating | 20 A continuous for a full discharge with cells below 60 °C from 25 °C ambient in an open-air mount (back and lid faces open); 35 A peak for 10 s. In any other mount or ambient, PACK_LIMITS derates the allowed discharge current (full to 50 °C cell temperature, linear to 5 A at 60 °C) so cells stay below 60 °C | Thermal and cell-current calculation; later load test | Met on paper: 51 °C in open air (56 °C with higher resistance); derates to about 18.6 A enclosed and 14 A from 45 °C |
| R4 | Charge time at the standard dock | 3 h or less from empty to full at 5 A; 80 % in 2 h or less | CC-CV charge calculation | Met |
| R5 | Mass for one-hand carry and swap | 3.5 kg or less (7.7 lb) including handle and connector | Mass budget; later weighing | Met: 3.03 kg (SWC-DDR-003) |
| R6 | Mechanical envelope (interface) | Body 340 x 90 x 80 mm, +0 / -1.5 mm; overall length with handle and plug 400 mm or less | Massing model, then drawing sheet | Met: 393 mm overall |
| R7 | Swap time and effort | Pack out of a dock or vehicle and a charged pack seated and latched in 10 s or less, one hand, no tools; insertion force 50 N or less | Design review; later timed trial | Not verifiable at TRL 3 |
| R8 | Ingress protection | Pack IP65, including the unmated connector face; dock IP54 for sheltered outdoor mounting | Design review of seals and contacts | Not verifiable at TRL 3 |
| R9 | Cycle life and state-of-health tracking | 500 cycles or more to 80 % of rated capacity at 0.5C charge and discharge, 25 °C; SoH estimate within ±5 % | Cell datasheet review; later cycling data. The 4.1 V fleet charge mode (decided) is the main mitigation | At risk |
| R10 | Blind-mate connector (interface) | 5,000 mating cycles or more; self-aligns over ±3 mm lateral and ±2° angular misalignment; 40 A continuous per power contact; contact sequence PACK- first, INTERLOCK last | Connector datasheet; design review. Family decided: custom keyed shroud with commercial contacts (SWC-DDR-002) | Not verifiable at TRL 3 |
| R11 | Protections | Cell overvoltage and undervoltage, charge and discharge overcurrent, short-circuit trip within 500 µs, over-temperature, charge lockout below 0 °C, cell-level fusing, pre-charge, output dead when unmated | BMS specification review; later fault injection | Not verifiable at TRL 3 |
| R12 | Data interface and logging (interface) | CAN 2.0B at 250 kbit/s with a published message set; pack stores 2,000 or more cycle records; any conforming dock reads and exports them as CSV without a cloud account; bit layout as published in SWC-PRC-001 v0.3 | Message set review, bus-load calculation; later bench decode | Met on paper |
| R13 | Wake for hosts without CAN or a wake supply (interface v0.3 item W) | Pack wakes from sleep when a receiver closes INTERLOCK through a 10 kΩ coding resistor, drawing no supply from the host; also wakes on WAKE (5 to 15 V) or its manual button; rejects a shorted or open loop; sleep drain 1 % of capacity per month or less; legacy discharge-only mode at 15 A for hosts without CAN | Calculation; later bench check | Met on paper |
| R14 | Charge-while-discharging mode (interface v0.3 item C) | Dock, station and vehicle hosts may request mode 4 (charge-discharge); pack allows net current between the allowed charge and allowed discharge limits without interrupting its output, and on a charge-side fault stops charge only and keeps discharge | Message set review; calculation; later bench check | Met on paper |
| R15 | Latch vibration rating for vehicles (interface v0.3 item V) | Class V1 vehicle receivers and the pack latch: no latch release and no power-contact interruption of 1 ms or longer under the UN 38.3 test T3 sine profile (7 to 200 Hz, peak 8 g) in three axes and 25 g, 11 ms half-sine shocks; latch proof load 1.72 kN along the insertion axis; receiver preload 330 N or more with 50 N or less hand force. Class D (gravity docks) needs no rating | Calculation; later vibration test (TRL 4, on hold) | Not verifiable at TRL 3 |
| R16 | Prototype cost scope | Parts for one pack and one wall dock at the USD 700 value-engineering target or under (`budget_usd` in `project.yaml`, a hypothetical control target, not a limit). A SwapCell pack is priced once, here, and excluded from each dependent kit budget | Priced BOM | Under the target: USD 619, USD 81 under |

## Assumptions

- A 48 V class pack is 13 lithium-ion cells in series. The 3.0 V per cell lower limit is conservative for most NMC and NCA cells; the BMS enforces it regardless of the vehicle controller cutoff.
- 20 A continuous (about 940 W) covers a 750 W cargo-trike motor with margin. E-bikes at 250 to 500 W draw 5 to 11 A.
- A fleet vehicle swaps once or twice a day. Over five years that is about 3,650 mating cycles, so R10 at 5,000 cycles has about 37 % margin (SWC-CAL-001). Dock-side contacts see more cycles than pack-side ones and should be replaceable.
- R5 and R7 assume an adult lifting from a wall dock at 0.8 to 1.2 m height. A lower mounting height would need a review of R5.
- R9 depends on the cell chosen. High-energy 21700 cells often quote fewer cycles than high-power cells; see SWC-PRC-001.
- R13 to R15 were approved by Amish on 2026-09-25 as interface v0.3 additions. The specific values (10 kΩ coding, 100 µA sleep target, 25 g shock, 330 N preload) were engineering proposals inside those additions; Amish confirmed them on 2026-09-25 (SWC-DDR-002).
- R15 uses the UN 38.3 test T3 vibration profile because every pack must pass it for transport anyway; the 25 g shock is a proposed curb-strike level for rigid cargo vehicles.
- R16: the USD 700 value-engineering target covers the parts for one pack and one dock. A second pack for a real swap demonstration (about USD 449 more, about USD 1,068 in total with the constructable design) is a build budget, to be set before any build as Amish decided on 2026-09-25 (SWC-DDR-002); it is on hold with TRL 4.

> **Safety:** The pack is a 468 Wh lithium-ion battery at up to 54.6 V DC that can deliver about 500 A into a short. R11, R13 (reject a shorted INTERLOCK loop) and R14 (never charge below 0 °C, even in charge-discharge mode) are safety requirements, not conveniences.

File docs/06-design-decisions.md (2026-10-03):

---
doc_id: SWC-DEC-001
title: SwapCell design decisions register
project: SwapCell
doc_type: Design decisions register
version: "0.3"
status: Draft
date: '2026-10-02'
author: Amish Chadha
license: CERN-OHL-S-2.0
revisions:
- version: "0.1"
  date: '2026-10-01'
  author: Amish Chadha
  change: Register opened with the open items of SWC-DDR-001 to 003, the 2026-09-26 render review and the build plan work
- version: "0.2"
  date: '2026-10-02'
  author: Amish Chadha
  change: "Amish approved the recommendations for all open decisions 1 to 13 on 2026-10-02 (SWC-DDR-003 accepted; interface v0.4 handle zone and catch geometry; polycarbonate sheet lid; LFP code reserved; EnergyBus deferred); moved to decisions made"
- version: "0.3"
  date: '2026-10-02'
  author: Amish Chadha
  change: "Cost line updated for the polycarbonate sheet lid (USD 619, USD 81 under the target)"
---

# SwapCell design decisions register

Every design decision still to be made, and every decision made, in one place. Each decision is argued in full in its decision record under `docs/decisions/` or in the review note (`docs/REVIEW.md`); this register is the index Amish works from. The build plan (`docs/05-build-plan.md`) describes the design as it stands and does not list open decisions.

## Open decisions

None. All open decisions were decided on 2026-10-02.

## To confirm when parts are bought

| # | What to confirm | Why it matters | Source |
| --- | --- | --- | --- |
| 1 | The power and signal contact parts, their diameters and lengths | They set the hole sizes in the plug and receptacle shrouds and the mating order; R8 and R10 depend on them | SWC-DDR-002, SWC-DDR-003 |
| 2 | The cell model: diameter 21.0 to 21.2 mm, datasheet cycle life | The holder pockets are 21.2 mm; R9 stays at risk until a cell is named | SWC-DDR-001, SWC-CAL-001 |
| 3 | The battery management board's size (about 230 x 58 mm, 10 mm or less thick) and mounting holes | They set the four holes in the right side wall | SWC-DDR-003 |
| 4 | The wake button's depth behind the panel, 15 mm or less | The cells are 2.7 mm behind the modelled switch body | SWC-DDR-003 |
| 5 | The charger's size (modelled 150 x 64 x 110 mm) | The straps and their tapped holes are sized to it | SWC-DDR-003 |
| 6 | The controller box size (modelled 50 x 50 x 30 mm) | It must fit between the charger and the shelf retainer | SWC-DDR-003 |
| 7 | M3 press-in nuts rated for 1.5 mm 5052 aluminium | The lid's eight screws go into them | SWC-DDR-003 |

## Value engineering

Value-engineering target: USD 700 (a hypothetical control target, not a limit). Estimated cost of the constructable design: USD 619 (USD 81 under the target): USD 449 for the pack and USD 170 for the dock. Main cost drivers and savings worth trying:

- The largest lines are the 26 cells (USD 143), the battery management board (USD 120), the charger (USD 60), the plug and receptacle with their contacts (USD 60 together), the dock cradle (USD 40) and the fuses and wiring (USD 36).
- Making the design constructable added USD 47 (SWC-DDR-003): the latch housing, slider and springs (USD 10), the cell holder frames (USD 6, moved from the wiring line, which fell by USD 4), the dock mounting parts (USD 15), the longer back plate (USD 10), the tray flanges (USD 5) and more fixings (USD 5).
- Savings worth trying: a 6 mm back plate instead of 12 mm (about USD 10 and 1.5 kg less; the loads are small); cells and boards bought for several packs at once; printing the shelf and guides at lower infill; a stock enclosure-style charger with mounting ears, which would drop the straps.

## Decisions made

| Date | Decision | Decided by | Record |
| --- | --- | --- | --- |
| 2026-09-25 | TRL 2 review items 1 to 10: 13S2P of 5 Ah 21700 cells; aluminium tray with a printed flame-retardant lid; interface v0.2; SwapCell message profile with an EnergyBus gateway study; legacy discharge-only mode at 15 A; health log in the pack; dock switches a certified 5 A charger; 4.1 V fleet mode; interface governance in this repo; `budget_usd` kept at 700 | Amish: "proceed with all of your recommendations across all batches. Make sure we don't proceed to TRL 4 on any of them." | SWC-DDR-001 |
| 2026-09-25 | Interface v0.3 additions: wake for hosts without CAN (W), charge-while-discharging mode (C), latch vibration rating for vehicles (V); shared packs priced once, here | Amish, cross-cutting approval | SWC-DDR-001, items 11 to 13 |
| 2026-09-25 | Connector family (custom keyed shroud with commercial contacts); values inside W, C and V confirmed (10 kΩ coding, 100 µA sleep, 25 g shock, 330 N preload, charge-FET fallback); R3 kept at 20 A with temperature derating; build budget for a second pack set before any build | Amish: "i accept all your recommendations, go with them across all repos." | SWC-DDR-002 |
| 2026-09-25 | TRL 4 on hold for every repo | Amish: "Make sure we don't proceed to TRL 4 on any of them." | SWC-DDR-001, `docs/REVIEW.md` |
| 2026-09-30 | Make the design physically buildable while drawing the build plan | Amish: "If you are realising that the design cannot be built as per concept - fix the design assumptions to match and be physically feasible as you draw the illustrations." | SWC-DDR-003 (accepted on 2026-10-02, below) |
| 2026-09-30 | Open decisions are kept in this register, not in the build plan | Amish: "don't log outstanding decisions in this build plan - that is not the place for it. that should be in a separate design document logged and named as such" | This register |
| 2026-10-01 | `budget_usd` is a value-engineering target, not a limit | Amish: "the budgets are a hypothethical control target to ensure we are thinking along a value engineering lens. its ok to ensure wording reflects that the hypothesis budget was x - the real cost being accrued is y" | SWC-CAL-001 v0.3, this register |
| 2026-10-02 | Design for construction accepted: the changes P1 to P12 of SWC-DDR-003 and their knock-on changes, as made | Amish: "i approve your recommendations for all 555 open decisions." | SWC-DDR-003, Tables 1 and 2 |
| 2026-10-02 | Handle zone (option a): widened in interface v0.4 to 84 x 43 mm, from the zone's front edge to the back face, so receivers leave the thumb button clear | Amish: "i approve your recommendations for all 555 open decisions." | SWC-DDR-003, A1 |
| 2026-10-02 | Catch geometry (option a): published in interface v0.4 (latching face 1 mm above the pawl, 8 mm reach, 4 mm engagement, 6 mm pawl projection, 5 mm travel), so every receiver latches the same way | Amish: "i approve your recommendations for all 555 open decisions." | SWC-DDR-003, A2 |
| 2026-10-02 | Lid (option b) for the prototype: cut from 3 mm UL 94 V-0 polycarbonate sheet. This changes the printed-lid decision of 2026-09-25 (SWC-DDR-001, item 2) for the prototype; the drawing allows either | Amish: "i approve your recommendations for all 555 open decisions." | SWC-DDR-003, A3; SWC-DDR-001 |
| 2026-10-02 | Thermal path (option a): the 0.10 K/W core-to-tray assumption is kept and checked in the TRL 4 load test, with the battery board's temperature sensor placed on the rear row of cells, now furthest from the tray | Amish: "i approve your recommendations for all 555 open decisions." | SWC-DDR-003, A4 |
| 2026-10-02 | First co-design partner: kept open under the portfolio rule, but an urban cargo-bike or e-bike delivery fleet is approached first, with a repair workshop second | Amish: "i approve your recommendations for all 555 open decisions." | SWC-DDR-001, item 14 |
| 2026-10-02 | LFP variant: not added now; a chemistry code in the message set and a coding key are reserved so an LFP pack can never take an NMC charge or the reverse | Amish: "i approve your recommendations for all 555 open decisions." | SWC-DDR-001, item 16 |
| 2026-10-02 | EnergyBus gateway: deferred; the native SwapCell profile stays the reference, and CiA 454 is read only when a partner needs EnergyBus | Amish: "i approve your recommendations for all 555 open decisions." | SWC-DDR-001, item 18 |
| 2026-10-02 | Render pose: the lifted pose is kept for the hero render | Amish: "i approve your recommendations for all 555 open decisions." | `docs/REVIEW.md`, 2026-09-26, item 1 |
| 2026-10-02 | State-of-charge light bar accepted as an optional pack feature under line 14, outside the interface | Amish: "i approve your recommendations for all 555 open decisions." | `docs/REVIEW.md`, 2026-09-26, item 2 |
| 2026-10-02 | Dock status light accepted under line 11 | Amish: "i approve your recommendations for all 555 open decisions." | `docs/REVIEW.md`, 2026-09-26, item 3 |
| 2026-10-02 | Thumb release behind the handle accepted; it follows from decision 2 above | Amish: "i approve your recommendations for all 555 open decisions." | `docs/REVIEW.md`, 2026-09-26, item 4 |
| 2026-10-02 | Finish and colours (slate tray, light grey lid, graphite handle, teal accents) accepted as the reference look | Amish: "i approve your recommendations for all 555 open decisions." | `docs/REVIEW.md`, 2026-09-26, item 5 |

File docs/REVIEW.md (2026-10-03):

# Review note: SwapCell

## Session 2026-09-24: /populate to a strong TRL 2

### What was done

- `docs/01-problem.md` (SWC-PRB-001 v0.2): problem, users and context (fleets, rural users, repair shops, builders, portfolio integrators), constraints, out of scope, prior work described without links.
- `docs/03-requirements.md` (SWC-REQ-001 v0.2): 12 measurable requirements (R1 to R12) with targets and planned verification. R6, R10 and R12 are the interface requirements.
- `docs/02-concept.md` (SWC-PRC-001 v0.2): how it works, components table, first-order numbers with assumptions, interface definition (mechanical envelope, 8-contact pinout, CAN message set outline and behavior rules), design choices, safety, open questions.
- `cad/src/concept_media.py`: massing model of the pack (tray, 26-cell block, BMS, lid, plug, handle, latch) seated in the wall dock (cradle, receptacle, charger, controller), with a wall and hand for scale.
- `media/`: hero, blueprint sheet SWC-DWG-001 (PNG, PDF, SVG), cutaway, exploded view with BOM callouts 1 to 11, energy flow diagram with estimates, `model.glb` and `viewer.html`.
- `bom/bom.csv`: 13 lines with indicative prices, numbered to match the exploded view; `bom/bom-notes.md`.
- `README.md`: hero image and media links above "Problem".
- `docs/pdf/`: branded PDFs of the three controlled documents.

### Key results (estimates, to be checked at TRL 3)

| Quantity | Estimate | Requirement |
| --- | --- | --- |
| Configuration | 13S2P, 26 x 21700 at 5.0 Ah | |
| Voltage and energy | 46.8 V nominal, 10 Ah, about 468 Wh | R1, R2 met |
| Cell current | 10 A continuous, 17.5 A peak per cell (rated 25 A) | R3 electrically met |
| Temperature at 20 A full discharge | about 61 °C from 25 °C (adiabatic, 44 W) | R3 **at risk** |
| Mass | about 2.8 kg | R5 met |
| Body | 340 x 90 x 80 mm; about 393 mm overall | R6 met |
| Charge time at 5 A | about 2.3 h full, 1.2 h for 20 to 80 % | R4 met |
| Energy per cycle | about 550 Wh in, 454 Wh at pack terminals | |
| Parts cost | about $370 per pack, $145 per dock, $515 total | Within $700 |

Requirements not met or at risk:

- **R3 (thermal):** 20 A continuous for a full discharge reaches about 61 °C in the adiabatic worst case, just over the 60 °C target, and would fail from 45 °C ambient. Either derate to about 15 A continuous or show heat loss through the aluminium tray at TRL 3.
- **R9 (cycle life):** typical 5 Ah 21700 cells give about 300 to 500 cycles to 80 %, so 500 cycles is at risk without a 4.1 V fleet charge mode or a longer-life cell.
- **R7, R8, R10:** cannot be judged until a connector family and seals are chosen; no known conflict.

### Proposed, awaiting Amish

1. Cell configuration: 13S2P of 5 Ah 21700 cells (recommended). Alternatives: 13S3P of 18650 cells, or 13S4P of 21700 (about 5 kg) as a later "double" variant.
2. Housing: aluminium tray with a printed flame-retardant lid (recommended), or all-printed.
3. Interface v0.2 as written in SWC-PRC-001: envelope 340 x 90 x 80 mm, 2 power plus 6 signal contacts with a last-mate interlock, CAN 2.0B at 250 kbit/s with 11-bit IDs.
4. Message set: an open SwapCell profile now with an EnergyBus (CiA 454) gateway study at TRL 3 (recommended), or adopt EnergyBus directly.
5. Legacy mode for non-CAN vehicles: discharge only at 15 A (recommended), or CAN always required.
6. State-of-health log stored in the pack and read by any dock; no cloud dependency.
7. Dock switches a certified 5 A charger; no custom mains electronics.
8. Fleet charge mode at 4.1 V per cell, selectable by the dock.
9. Interface governance: a versioned interface section in this repo, changes approved by Amish, which SunSpoke, PowerBox, FieldCell and WaterWalker build to.
10. First co-design partner: a repair workshop (recommended), a delivery fleet or a rural e-bike cooperative.
11. Budget: $700 in `project.yaml` is kept and covers one pack and one dock. A second pack for a real swap demonstration would raise the parts total to about $885. Proposed: keep $700 for TRL 3 (paper work only) and decide on about $900 before any build. Awaiting Amish.

### Safety concerns

- 470 Wh lithium-ion pack: thermal runaway and propagation between cells is the main hazard. Cell spacing, barriers, venting and a flame-retardant liner are listed but not yet designed.
- Exposed connector contacts at up to 54.6 V DC with very high short-circuit current: the dead-output-until-interlock rule is essential and must survive the TRL 3 BMS specification.
- Sudden loss of power while riding: the warn-then-derate rule must be kept.
- Transport: the pack is above 100 Wh, so it is Class 9 dangerous goods (UN 3480 or 3481) and needs UN 38.3 testing before commercial shipping.
- Any future build and test must happen inside a fireproof enclosure, never unattended. No build work was started in this session.

### Recommended next step

Review this note, the interface section of SWC-PRC-001 and the media. If approved, run `/advance-trl3` to do the thermal model for R3, the cell selection for R9, the connector family selection for R10, the full CAN bit layout, and the parametric model and drawing sheet of the envelope. Share the interface section with the SunSpoke, PowerBox, FieldCell and WaterWalker repos only after Amish approves it.

## Session 2026-09-25: TRL 3

Amish's instruction for this session (2026-09-25): "proceed with all of your recommendations across all batches. Make sure we don't proceed to TRL 4 on any of them." He also approved three SwapCell interface additions (wake for hosts without CAN, charge-while-discharging mode, latch vibration rating for vehicles) and the rule that shared SwapCell packs are priced once. TRL 4 is on hold by his instruction.

### What was done

- `docs/decisions/0001-trl2-review-decisions.md` (SWC-DDR-001 v0.1): every decided item, the three v0.3 additions, and the items still open.
- `docs/02-concept.md` (SWC-PRC-001 v0.3): issues **SwapCell interface v0.3** (items W wake, C charge-discharge, V latch classes D and V1, L full CAN bit layout); decisions recorded; key numbers replaced with checked values; safety updated.
- `docs/03-requirements.md` (SWC-REQ-001 v0.3): status column; new R13 (wake), R14 (charge-discharge), R15 (latch class V1), R16 (budget scope and shared-pack pricing).
- `docs/01-problem.md` (SWC-PRB-001 v0.3): dependents and their needs, budget scope, open questions.
- `docs/04-calcs/01-sizing.md` (SWC-CAL-001 v0.1) with `docs/04-calcs/sizing.py` and `results.csv`: electrical, mass, lumped thermal with heat loss, charging and energy chain, wake and sleep, charge-discharge, latch, connector, CAN load and log, cost, and the full requirement table.
- `cad/src/model.py`: parametric build123d model (interface dimensions as parameters) exporting `cad/step/swapcell-{pack,dock,assembly}.step` and matching STL files.
- `cad/src/sheets.py` and `cad/drawings/SWC-DWG-002.{svg,pdf,png}`: general arrangement at Rev P1, "CONCEPT, NOT FOR FABRICATION" and "PRELIMINARY, NOT FOR FABRICATION".
- `bom/bom.csv` (14 lines, all priced, with supplier types) and `bom/bom-notes.md`.
- `cad/src/concept_media.py` now builds from `model.py`; all media regenerated and checked by eye (hero, cutaway, exploded, flow, blueprint SWC-DWG-001, `model.glb`, `viewer.html`).
- `project.yaml`: `trl: 3`, `trl_target: 3`, evidence listed. `README.md`: TRL 3, key components, links.

### Requirements (SWC-CAL-001)

Not met: **none**. At risk: 3. Not verifiable at TRL 3: 5. Met: 8 (three of them on paper only).

| ID | Status | Value |
| --- | --- | --- |
| R3 | **At risk** | 51 °C open air at 20 A from 25 °C (56 °C with higher resistance); 63 °C enclosed; 71 °C from 45 °C ambient. About 14 A holds 60 °C from 45 °C |
| R9 | **At risk** | 300 to 500 cycles typical for the cell class; 4.1 V fleet mode is the mitigation |
| R2 | **At risk** | 10.0 Ah, 466 Wh nominal; 9.7 Ah, 452 Wh at the 4.85 Ah cell minimum |
| R7, R8, R10, R11, R15 | Not verifiable at TRL 3 | Insertion about 41 N (assumed contact forces); IP65 by design only; connector family not chosen; short-circuit 496 A, pre-charge 460 ms; latch proof 1.72 kN |
| R1, R4, R5, R6, R16 | Met | 46.8 V; 2.3 h full, 1.6 h to 80 %; 2.85 kg; 393 mm overall; $559 of $700 |
| R12, R13, R14 | Met on paper | CAN load 1.8 %; sleep drain 0.72 % per month; 3.8 A net charge in the PowerBox case |

Corrections to TRL 2 numbers: mass 2.8 to 2.85 kg, pack parts $370 to $414 (cell price $4.50 to $5.50, wake button added), energy chain 550/454 to 547/457 Wh, 0 to 80 % charge 1.6 h.

### Decisions recorded (SWC-DDR-001)

Decided by Amish, 2026-09-25, go with recommendation: 13S2P 21700 cells; aluminium tray with printed lid; interface v0.2 as written (superseded by v0.3); SwapCell message profile with an EnergyBus gateway study; legacy discharge-only mode at 15 A; SoH log in the pack; dock switches a certified 5 A charger; 4.1 V fleet mode; interface governance in this repo; `budget_usd` kept at $700 for one pack and one dock; solar DC dock variant later. Cross-cutting approvals: interface v0.3 items W, C and V, and shared packs priced once here.

### Still awaiting Amish

1. First co-design partner (left open by the portfolio rule).
2. Build budget of about $973 for two packs and one dock, only when TRL 4 is lifted.
3. LFP variant (no preference stated).
4. Connector family: recommended custom keyed shroud with commercial contacts.
5. Values chosen inside the approved additions: 10 kΩ coded INTERLOCK, 100 µA sleep, 25 g shock, 330 N receiver preload, charge-FET fallback.
6. R3: keep 20 A at 25 °C with temperature derating (recommended), or label 15 A.
7. EnergyBus mapping needs the CiA 454 specification, which was not read.

### For dependent repos

PowerBox, SunSpoke, StepGen, WaterWalker, CargoMule, FieldCell and others should cite "SwapCell interface v0.3" items W, C and V. The one change for any v0.2 receiver: fit a 10 kΩ coding resistor in the INTERLOCK loop instead of a direct link to SGND. Vehicle receivers must meet latch class V1 and leave the back and lid faces of the pack open to air (R3).

### Safety concerns

- 468 Wh lithium-ion pack; about 500 A available into a short. Thermal runaway and propagation are still not analyzed and can only be shown by test.
- R3: a pack enclosed tightly in a vehicle can exceed 60 °C at 20 A; derating in PACK_LIMITS is essential.
- The coded interlock stops a coin or wet debris from enabling the output, including in legacy mode. It must survive into any BMS firmware.
- Charge-discharge mode makes the host a charger; the pack must refuse charge below 0 °C and above 45 °C.
- A pack that leaves a vehicle mount is a heavy projectile with live contacts; latch class V1 is a safety item.
- Transport as Class 9 dangerous goods with UN 38.3 before any shipping. No build work was started.

### Notes against the standard

- The TRL change is recorded here and in SWC-DDR-001, not in `build-log/`, because new build-log entries would read as TRL 4 evidence.
- No TRL 4 material was found in the repo. `build-log/README.md` and the empty `electronics/` and `firmware/` folders were left untouched.
- No unchecked citations were listed, so no web verification was needed. BOM prices are estimates, not quotes.

### Recommended next step

Amish reviews SWC-DDR-001 items 14 to 20 and the interface v0.3 section of SWC-PRC-001, then approves v0.3 for circulation to the dependent repos. **TRL 4 is on hold by Amish's instruction.** For the record only, TRL 4 would need: a chosen cell model and connector family, a BMS configuration that implements the v0.3 wake, charge-discharge and interlock rules, a pack built and charged in a fireproof enclosure, lab test reports (TST, `environment: lab`) for capacity, temperature at 20 A, protections and latch class V1, build-log entries, and a build budget decision.

## Session 2026-09-25: recommendations accepted

Amish's instruction (2026-09-25, in chat): "i accept all your recommendations, go with them across all repos." Every open item with a recommendation is now **Decided by Amish, 2026-09-25: go with recommendation**, recorded in `docs/decisions/0002-recommendations-accepted.md` (SWC-DDR-002 v0.1). TRL 4 remains on hold.

### Decisions applied and what changed

| Item (SWC-DDR-001 #) | Decision | Before | After |
| --- | --- | --- | --- |
| 20, R3 thermal rating | Keep 20 A at 25 °C with PACK_LIMITS temperature derating | R3 "20 A from 25 °C ambient", **at risk** (51 °C open air, 63 °C enclosed) | R3 restated: 20 A in an open-air mount from 25 °C; elsewhere derate (full to 50 °C cell temperature, linear to 5 A at 60 °C). Sustained current about 18.5 A enclosed, 14.0 A from 45 °C. **Met on paper** |
| 17, connector family | Custom keyed shroud with commercial contacts | "Proposed, awaiting Amish" | Decided; contact parts chosen at supplier selection (TRL 4, on hold). No geometry change |
| 19, values inside W, C, V | Confirmed as proposed | 10 kΩ, 100 µA, 25 g, 330 N, charge-FET fallback awaiting confirmation | Same values, confirmed |
| 15, build budget | Keep $700 at TRL 3; set the build budget (about $973) before any build | Open | Decided, on hold with TRL 4. `budget_usd` unchanged at $700 |

Files changed: SWC-PRC-001 v0.3 to v0.4 (derating rule, connector decision, confirmed values, open questions); SWC-REQ-001 v0.3 to v0.4 (R3 restated, R10 note, assumptions); SWC-CAL-001 v0.1 to v0.2 and `docs/04-calcs/sizing.py` (new enclosed derating current, R3 status, R10 value; `results.csv` regenerated); SWC-DDR-001 v0.1 to v0.2 (items 15, 17, 19 and 20 marked decided); `bom/bom.csv` item 5 note; `bom/bom-notes.md`; SWC-DWG-002 Rev P1 to P2 (notes for connector and R3 derating; geometry unchanged); `project.yaml` evidence list; `README.md` new sections "Concept rationale", "Burning platform", "Where it could be used" and "What sparked the idea". STEP, STL, drawing, concept media and all PDFs regenerated, with designmolecule.com in the footers.

### Requirement status (SWC-CAL-001 v0.2)

Not met: **none**. At risk: 2 (was 3). Not verifiable at TRL 3: 5. Met: 9 (four on paper only).

| ID | Status | Value |
| --- | --- | --- |
| R2 | **At risk** | 10.0 Ah, 466 Wh nominal; 9.7 Ah, 452 Wh at the cell minimum |
| R9 | **At risk** | 300 to 500 cycles typical; 4.1 V fleet mode is the mitigation |
| R7, R8, R10, R11, R15 | Not verifiable at TRL 3 | Need hardware and test (TRL 4, on hold) |
| R1, R4, R5, R6, R16 | Met | Unchanged; $559 of $700 |
| R3, R12, R13, R14 | Met on paper | R3 51 °C open air (56 °C with higher resistance), derating elsewhere |

### Still awaiting Amish

1. First co-design partner (no recommendation; portfolio rule).
2. LFP variant (no preference stated).
3. EnergyBus gateway mapping (needs the CiA 454 specification; no recommendation).

### Cross-repo actions

None required. The interface stays v0.3 and the confirmed values match what dependent repos cite. For information only: PowerBox, SunSpoke, StepGen, WaterWalker, CargoMule and FieldCell vehicle or station receivers keep the full 20 A only if they leave the back and lid faces of the pack open to air; in an enclosed mount the pack now derates itself to about 18.5 A.

### TRL

`trl: 3` and `trl_target: 3` unchanged. **TRL 4 remains on hold by Amish's instruction.** No build, test, purchase, PCB or firmware work was started.

## Session 2026-09-26: product appearance model and photoreal renders

Amish chose this repo for the first batch of product renders on 2026-09-26. This session added a product appearance model for photoreal renders; the massing model, BOM and documents are unchanged.

### What was done

- New `cad/src/product_model.py`: `product_parts()` (53 parts in the groups shell, internal and context), `TITLE` and `RENDER_VIEWS` (hero, exploded and a detail view without the wall). All main dimensions and interfaces come from `PARAMS` in `cad/src/model.py`.
- Pack: folded tray with 6 mm bend radii and rounded ends, lid with a parting-line groove and six M3 screws, flush teal wake button with a ring mark, interface label and wordmark, rating label on the side, latch doubler rivets, carry handle with a ribbed rubber grip, steel latch pawl with a teal thumb release, keyed plug shroud with visible power and signal contacts.
- Pack internals: 26 cells with wraps and end caps, cell holders, nickel strips, BMS board with FETs, heatsink, connectors, capacitors and main fuse, and the two power leads to the plug.
- Dock: brushed back plate with wall screws, cradle shelf with a wordmark, side guides with lead-in chamfers, steel latch catch, receptacle with mating contacts in the pocket, finned charger with a status light, cable gland and mains cord, controller box with a parting line, status light and microSD slot.
- Context: a compact painted wall section and a cord grommet.
- `README.md`: hero image now points to `media/render-hero.png`, with a link to `media/render-exploded.png`. The render files are produced separately.

### Differences from model.py (appearance only)

1. **Render pose.** The pack is shown lifted 110 mm above its seated position, still between the guides, to show a swap in progress; model.py shows it seated. Proposed, awaiting Amish. Recommendation: keep the lifted pose for the hero, since it shows the receptacle and the guides.
2. **State-of-charge light bar.** A five-segment light bar behind a clear lens below the wake button, lit by the wake button press. It is not in interface v0.3 or the BOM. Proposed, awaiting Amish. Recommendation: accept as an optional pack feature under BOM item 14, outside the interface, or remove it from the renders.
3. **Dock status light.** A light strip on the front of the cradle shelf, driven by the dock controller; not in the BOM. Proposed, awaiting Amish. Recommendation: accept under BOM item 11.
4. **Thumb release.** Shown as a small ribbed tab on the pack top behind the handle; the precis says only "thumb release under the handle". Proposed, awaiting Amish. Recommendation: accept the position for the renders; the mechanism stays undefined at TRL 3.
5. **Finish and colours.** Tray painted slate grey, lid light grey, handle graphite with a black rubber grip, teal accents, printed labels and wordmarks. Proposed, awaiting Amish. Recommendation: accept as the reference look.

### TRL

This is an appearance model only: no tolerances, fabrication detail, PCB layouts or build work. `trl: 3` is unchanged and **TRL 4 remains on hold by Amish's instruction.**

## Session 2026-09-27: kit 1.5.0 and image quality

- Kit 1.5.0 synced: STANDARDS v1.5 (sections 12 to 15: product renders, storefront images and image quality, public release, authorship and signing), `.kit/cards.py`, `.kit/image_qc.py`, `.kit/release_gate.py`, issue templates, and the `/render-product` and `/release` commands. `CLAUDE.md` now matches `.kit/CLAUDE.md`.
- Every `media/render-*.png` recaptioned from its original render with the new layout: the title, concept label and repository sit in a band above the render and the view note in a band below it, each line wrapped to the image width, so no text overlaps other text or the render or runs off the image. `media/card.png` and `media/social-preview.png` regenerated with the same rules.
- `python .kit/image_qc.py` and `python .kit/release_gate.py` pass. trl stays 3.

## Session 2026-10-01: constructable design and prototype build plan (kit 1.7.0)

Amish's instructions: approve the build plan format and extend it to every repo (2026-09-30), keep open decisions out of the build plan and in a separate register (2026-09-30), make the design physically buildable while drawing the illustrations (2026-09-30), and treat `budget_usd` as a value-engineering target (2026-10-01). TRL stays 3; TRL 4 remains on hold. Nothing was built or bought.

### What was done

- Kit 1.7.0 installed (`.kit/`, `.claude/commands/`); `CLAUDE.md` replaced by `.kit/CLAUDE.md`.
- Constructability review of `cad/src/model.py` with build123d: the old model had the receptacle inside the solid shelf (25,000 mm³ overlap), the guides and controller box floating off the back plate, the controller 35 mm past the plate's edge, the latch catch below the pawl, and no fixing for the lid, plug, handle, cells, BMS, charger, shelf or guides.
- `cad/src/model.py` rewritten: every component built as made or bought, with its fixings; `python cad/src/model.py --check` runs 71 constructability checks, all passing. STEP and STL regenerated.
- New decision record `docs/decisions/0003-design-for-construction.md` (SWC-DDR-003, Draft, open for Amish's review).
- `bom/bom.csv`: lines 1, 4 to 9 and 11 to 13 updated; lines 15 (latch housing, release slider and springs), 16 (cell holder frames) and 17 (dock mounting parts) added. `bom/bom-notes.md` updated.
- Calculations re-run (`docs/04-calcs/sizing.py`, `results.csv`): SWC-CAL-001 v0.3, SWC-REQ-001 v0.5, SWC-PRC-001 v0.5 updated for mass, thermal, cost and the latch.
- General arrangement SWC-DWG-002 Rev P3; concept media regenerated (`media/hero.png`, `cutaway.png`, `exploded.png`, `flow.png`, `concept-blueprint.*`, `model.glb`, `viewer.html`).
- `cad/src/build_plan_media.py` (uses `.kit/build_views.py`): overview, 15 making sketches (`cad/drawings/SWC-DWG-101` to `115`), 9 joint close-ups, 17 assembly step pictures and a block wiring diagram in `docs/05-build-plan/`.
- `docs/05-build-plan.md` (SWC-BLD-001 v0.1) and `docs/06-design-decisions.md` (SWC-DEC-001 v0.1) written; both added to `trl_evidence`; `design_state: constructable` in `project.yaml`; README links line and "Building the prototype" section added.

### Design changes made for construction (SWC-DDR-003)

1. Latch catch moved from 2 mm below the pawl to 1 mm above it, as a separate steel bar on two M5 screws, so the pawl hooks 4 mm under it.
2. Pawl redesigned: 6 mm proud (was 10), sliding in a riveted 1.5 mm steel housing (the latch doubler), pushed out by two springs and pulled in 5 mm by a ramped release slider under a thumb button just behind the grip.
3. Cell block moved 8 mm toward the lid to make room for the latch, held in two printed holder frames on the back wall.
4. Tray given 8 mm inward front flanges with eight M3 press-in nuts; lid on a 1 mm flat gasket with eight countersunk screws; tray 1 mm shallower so the body stays 80 mm deep.
5. Plug shroud fixed by four M3 screws from inside, with a 42 x 22 mm lead opening; contacts fitted through it.
6. Handle fixed by two M5 screws from inside into heat-set inserts.
7. BMS on four standoffs with countersunk screws through the right side wall.
8. Receptacle moved out of the solid shelf into a cavity under the pocket, captured by its flange on a foam pad and retainer plate, floating 3 mm each way; key post moved to the receptacle.
9. Side guides extended back to the plate and screwed from behind; 10 mm lead-in modelled.
10. Shelf and catch screwed from behind the plate.
11. Controller box moved onto the plate between the charger and the shelf.
12. Charger held by two folded straps; back plate lengthened from 520 to 580 mm.

### Key results

- Constructability checks: 71 of 71 pass.
- Pack mass 3.03 kg (was 2.85 kg); R5 (3.5 kg) still met. Energy density 154 Wh/kg.
- Thermal: hot spots unchanged (51, 63, 71 °C); enclosed derating current 18.6 A (was 18.5 A).
- Cost: value-engineering target USD 700; estimated cost of the constructable design USD 606 (USD 94 under the target); pack USD 436, dock USD 170.
- Requirement status unchanged: none not met; R2 and R9 at risk; R7, R8, R10, R11 and R15 not verifiable at TRL 3.
- Published interface values unchanged.

### Proposed, awaiting Amish

All listed in `docs/06-design-decisions.md`: acceptance of SWC-DDR-003; widening the handle zone to cover the thumb button (interface v0.4); publishing the catch geometry (interface v0.4); lid cut from V-0 sheet instead of printed; keeping the thermal assumption with the cells off the back wall; and the items carried over (co-design partner, LFP variant, EnergyBus mapping, the five render appearance items of 2026-09-26).

### Stale, to regenerate on Amish's Mac

`media/render-hero.png`, `media/render-exploded.png`, `media/render-detail.png`, `media/card.png` and `media/social-preview.png` still show the concept (six lid screws, a 10 mm pawl, guides off the plate, a shorter back plate, no charger straps). `cad/src/product_model.py` reads its sizes from the model and was not edited; it renders the 6 mm pawl from the new parameters.

### Safety concerns

- Unchanged hazards: 468 Wh lithium-ion pack, about 500 A into a short; thermal runaway not analyzed. The build plan carries seven safety stops, including building, charging and testing only inside a fireproof enclosure, never unattended.
- The latch now retains the pack in the dock (class D). Class V1 vehicle retention still needs the TRL 4 vibration test.
- Every screw and rivet head on the pack's published faces is countersunk, so nothing can snag a receiver or short against it.

### Recommended next step

Amish reviews SWC-DDR-003 and the register items 1 to 5. If accepted, issue interface v0.4 with the handle-zone and catch clarifications and tell the dependent repos. TRL 4 remains on hold.

## Session 2026-10-02: open decisions decided

On 2026-10-02 Amish approved the recommendations for every open decision: "i approve your recommendations for all 555 open decisions." The 13 open decisions of the design decisions register are now in its Decisions made table, dated 2026-10-02.

SWC-DDR-003 (design for construction) is accepted, with A1 to A4 decided as recommended. The SwapCell interface is issued as v0.4 in SWC-PRC-001: the handle zone is 84 x 43 mm, the catch geometry is published, and a chemistry code and coding key are reserved for a future LFP variant. A3 changes Amish's printed-lid decision of 2026-09-25 for the prototype (review flag 2): the lid is cut from 3 mm UL 94 V-0 polycarbonate sheet. Items 14, 16 and 18 of SWC-DDR-001 are recorded as decided. Item 12 was decided with item 2 (review flag 1).

### Documents changed

- `docs/06-design-decisions.md` (SWC-DEC-001 v0.2)
- `docs/decisions/0003-design-for-construction.md` (SWC-DDR-003 v0.2)
- `docs/decisions/0001-trl2-review-decisions.md` (SWC-DDR-001 v0.3)
- `docs/decisions/0002-recommendations-accepted.md` (SWC-DDR-002 v0.2)
- `docs/01-problem.md` (SWC-PRB-001 v0.4)
- `docs/02-concept.md` (SWC-PRC-001 v0.6)
- `docs/03-requirements.md` (SWC-REQ-001 v0.6)
- `docs/05-build-plan.md` (SWC-BLD-001 v0.2)
- `bom/bom-notes.md` (not a controlled document)
- `README.md` (not a controlled document)

### Follow-up actions to carry approved decisions into the design

1. Decision 2: Drawings: show the 84 x 43 mm handle zone on the interface drawing and on SWC-DWG-001.
2. Decision 3: Drawings: add the catch geometry (latching face, reach, engagement, pawl projection and travel) to the interface drawing and the dock catch making sketch.
3. Decision 2: Ask the repos that build to the interface to move from v0.3 to v0.4 and check their receivers leave the wider handle zone clear and use the published catch geometry (cargomule, cellguard, coldpod, culvertcrawl, dewdrive, dockhub, dustrunner, fieldcell, flattrike, lumaflow, motioncore, powerbox, stepclimber, stepgen, sunspoke, wastewise-scan, waterwalker, waterwatch, zeerbox).
4. Decision 2: Firmware: report interface minor version 4 in PACK_STATUS when the firmware is written or next changed.
5. Decision 4: BOM: change line 4 to 3 mm UL 94 V-0 polycarbonate sheet, with a sheet supplier and price; drop the large-format printer note.
6. Decision 4: Drawings: make SWC-DWG-108 name polycarbonate sheet as the prototype material.
7. Decision 5: Model and build plan pictures: show the battery board's temperature sensor on the rear row of cells in the wiring figure.
8. Decision 7: Calculations and message set: assign the reserved LFP chemistry code value and the connector coding key geometry when an LFP variant is designed; add the key to the model then.
9. Decision 1: Renders: regenerate the photoreal renders, `media/card.png` and `media/social-preview.png` on Amish's Mac to show the accepted design (eight lid screws, 6 mm pawl, longer back plate, charger straps); items 9 to 13 follow with them.

### Points found in the review

1. Item 12 duplicates item 2: if item 2 is approved as (a), item 12 is decided with it.
2. Item 4 reverses a decision Amish already made (printed lid, 2026-09-25); the register should say so rather than treat it as new.

No CAD model, BOM quantity or price, calculation result or picture was changed. TRL stays at 3; TRL 4 remains on hold.

## Session 2026-10-02: approved follow-ups carried out

Amish approved on 2026-10-02 that every follow-up action from the open-decision sign-off be carried out ("APPROVED CHANGES, COMPLETE THESE"). Status of the nine follow-ups listed above:

1. Handle zone on the interface drawing and SWC-DWG-001: done. The general arrangement SWC-DWG-002 (Rev P4) now carries Detail A, the 84 x 43 mm handle zone on the top end with the handle and thumb button inside it, and its interface notes are headed v0.4. The concept blueprint SWC-DWG-001 key figures name interface v0.4 and the 84 x 43 mm zone. The model has a check that the handle, thumb button and screws above the top end lie inside the zone.
2. Catch geometry on the interface drawing and the catch making sketch: done. SWC-DWG-002 Rev P4 Detail B shows the latching face 1 mm above the pawl, 8 mm reach, 4 mm engagement, 6 mm pawl projection and 5 mm travel; SWC-DWG-112 Rev P2 lists the same sizes; the build plan's catch section states them. Three model checks hold the published values.
3. Ask the receiver repos to move to v0.4: not done here; outreach and work in other repos (listed under Cross-repo actions below).
4. Firmware to report interface minor version 4 in PACK_STATUS: not done; firmware is TRL 4 work and none is written yet.
5. BOM line 4: done. 3 mm UL 94 V-0 polycarbonate sheet cut to size by a plastics distributor, USD 25 (estimate: one cut piece of about 0.03 m² with a one-off cutting charge; was USD 12 of filament); the large-format printer note is dropped.
6. SWC-DWG-108 names polycarbonate sheet: done (Rev P2).
7. Board temperature sensor on the rear row of cells in the model and the wiring figure: done. The model has the sensor on the middle cell of the rear row, with three new checks (on the cell, clear of the tray and latch housing by 3 mm or more, on the rear row); the wiring figure (Figure 12) shows it as "T".
8. LFP chemistry code and coding key geometry: not done; the decision assigns them only when an LFP variant is designed.
9. Photoreal renders, `media/card.png` and `media/social-preview.png`: not done here; they are made on Amish's Mac. The appearance model and the render scenes are ready for them (below).

### Results

- Constructability checks: 78 of 78 pass (71 before, plus 3 for the sensor, 3 for the catch geometry and 1 for the handle zone). STEP and STL regenerated.
- Cost: Value-engineering target: USD 700. Estimated cost of the constructable design: USD 619 (USD 81 under the target). Pack USD 449, dock USD 170. `budget_usd` unchanged.
- Mass: unchanged at about 3.03 kg; the polycarbonate sheet has the density the calculation already used (1.20 g/cm³), and the sensor is part of line 12.
- Requirement status: no change. R16 stays under the target (USD 619).
- Appearance model (`cad/src/product_model.py`) brought into line with the constructable design: eight flush countersunk lid screws, polycarbonate sheet lid, 6 mm pawl and the thumb button behind the grip, rivets and holder screws on the back face, cells at the model's rows with the sensor, the 580 mm back plate at its model height, guides and catch at model positions, the two charger straps, the controller box on the plate between charger and shelf, wall screws at the model's wall holes, labels reading interface v0.4. RENDER_VIEWS unchanged (hero, exploded, detail). Render scenes exported to `/home/claude/renders/swapcell`.

### Documents changed

- `cad/src/model.py`, `cad/step/*.step`, `cad/stl/*.stl`
- `cad/src/sheets.py`, `cad/drawings/SWC-DWG-002.*` (Rev P3 to P4)
- `cad/src/build_plan_media.py`, `cad/drawings/SWC-DWG-108.*` and `SWC-DWG-112.*` (Rev P1 to P2), `docs/05-build-plan/wiring.png`
- `cad/src/concept_media.py`, `media/` concept set (hero, cutaway, exploded, flow, blueprint SWC-DWG-001, `model.glb`, `viewer.html`)
- `cad/src/product_model.py`
- `bom/bom.csv` (line 4, line 3 note), `bom/bom-notes.md`
- `docs/04-calcs/sizing.py`, `docs/04-calcs/results.csv`, `docs/04-calcs/01-sizing.md` (SWC-CAL-001 v0.3 to v0.4)
- `docs/02-concept.md` (SWC-PRC-001 v0.6 to v0.7), `docs/03-requirements.md` (SWC-REQ-001 v0.6 to v0.7), `docs/05-build-plan.md` (SWC-BLD-001 v0.2 to v0.3), `docs/06-design-decisions.md` (SWC-DEC-001 v0.2 to v0.3), `README.md`
- All PDFs re-rendered.

### Cross-repo actions

- Move to interface v0.4 and check that receivers leave the 84 x 43 mm handle zone clear and use the published catch geometry: cargomule, cellguard, coldpod, culvertcrawl, dewdrive, dockhub, dustrunner, fieldcell, flattrike, lumaflow, motioncore, powerbox, stepclimber, stepgen, sunspoke, wastewise-scan, waterwalker, waterwatch, zeerbox. Their SwapCell cost citation also changes from USD 436 to USD 449 per pack.

No decision was made in this session beyond those Amish approved. TRL stays at 3; TRL 4 remains on hold.

## 2026-10-02: photoreal renders redone on the constructable design

Rendered with Blender Cycles on Amish's Mac from the updated appearance model; captioned with `.kit/photo_caption.py`; `media/card.png` and `media/social-preview.png` regenerated with `.kit/cards.py`. Views: hero, exploded, detail. image_qc passes. Appearance deviations are those logged above as proposed, awaiting Amish.

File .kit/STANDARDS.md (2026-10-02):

---
doc_id: OHP-STD-001
title: Documentation and drawing standard
project: Open Hardware Portfolio
doc_type: Standard
version: "1.7"
status: Released
date: 2026-09-30
author: Amish Chadha
license: CC-BY-SA-4.0
revisions:
  - version: "1.0"
    date: 2026-09-24
    author: Amish Chadha
    change: First release of the standard
  - version: "1.1"
    date: 2026-09-24
    author: Amish Chadha
    change: Adopt Technology Readiness Levels (section 9) for project maturity
  - version: "1.2"
    date: 2026-09-24
    author: Amish Chadha
    change: Portfolio phase cap (section 10), concept media standard (section 11), CLAUDE.md guardrails
  - version: "1.3"
    date: 2026-09-24
    author: Amish Chadha
    change: Scale figure, interactive 3D viewer and flow diagrams added to concept media; session slash commands
  - version: "1.4"
    date: 2026-09-26
    author: Amish Chadha
    change: Every sheet and render names the project and its GitHub repository; overall dimensions, ISO centre lines and 300 dpi PNG on sheets; titles name the device and view labels state the viewing direction; optional photoreal renders with Blender
  - version: "1.5"
    date: 2026-09-27
    author: Amish Chadha
    change: Product renders (section 12), storefront images and image quality check (section 13), public release and release gate (section 14), authorship, citation and commit signing (section 15)
  - version: "1.6"
    date: 2026-09-29
    author: Amish Chadha
    change: Licensing metadata with REUSE (section 16), Zenodo DOI and Software Heritage archiving (section 17), release gate checks REUSE and a single CITATION.cff license, archive.py
  - version: "1.7"
    date: 2026-09-30
    author: Amish Chadha
    change: Concept and constructable design states; design decisions register (DEC) kept apart from the build plan; prototype build plan (BLD, section 18) with pictures by component is required TRL 3 evidence; every repo targets TRL 3 during the populate phase; build_views.py; /to-trl3 and /build-plan commands
---

# Documentation and drawing standard

Every project in the portfolio uses this standard, so that each precis, write-up and sketch looks the same and carries its own version history. The standard ships as a kit in each repo's `.kit/` folder. The kit version is in `.kit/KIT_VERSION`.

## 1. Document types and IDs

Every controlled document has a unique ID in the form `PRJ-TYP-NNN`.

- `PRJ` is the three-letter project code listed in section 7.
- `TYP` is the document type code from the table below.
- `NNN` is a sequence number within that project and type, starting at 001.

| Code | Type | Typical file |
| --- | --- | --- |
| PRC | Design precis | `docs/02-concept.md` |
| PRB | Problem statement | `docs/01-problem.md` |
| REQ | Requirements | `docs/03-requirements.md` |
| CAL | Calculation or sizing note | `docs/04-calcs/*.md` |
| DDR | Design decision record | `docs/decisions/*.md` |
| BOM | Bill of materials | `bom/bom.csv` |
| DWG | Drawing or sketch sheet | `cad/drawings/*.svg` |
| BLD | Prototype build plan (section 18) | `docs/05-build-plan.md` |
| DEC | Design decisions register (section 18) | `docs/06-design-decisions.md` |
| TST | Test plan or test report (front matter adds `environment: lab` or `relevant`) | `docs/05-tests/*.md` |

Example: `TBK-PRC-001` is the ThermaBrick design precis.

## 2. Revision scheme

| Artifact | While in draft | When released | Change after release |
| --- | --- | --- | --- |
| Documents | 0.1, 0.2, 0.3 ... | 1.0 | 1.1 for minor edits, 2.0 for a design change |
| Drawings | Rev P1, P2 ... (preliminary) | Rev A | Rev B, C ... |

- Every change to a controlled document adds a row to its revision history before the commit.
- The `version` field in front matter always equals the newest row in `revisions`. The renderer rejects a document where they differ.
- Status is one of `Draft`, `In review`, `Released` or `Superseded`. Draft and In review documents print with a status band on every page.
- Every release is tagged in Git as `<doc_id>/v<version>`, for example `TBK-PRC-001/v1.0`. Drawings are tagged `TBK-DWG-001/revA`.
- Git history is the full audit trail. The in-document revision table is the human-readable summary.

## 3. Document front matter

Every Markdown document under version control starts with this block:

```yaml
---
doc_id: TBK-PRC-001
title: ThermaBrick design precis
project: ThermaBrick
doc_type: Precis
version: "0.1"
status: Draft
date: 2026-09-24
author: Amish Chadha
license: CERN-OHL-S-2.0
revisions:
  - version: "0.1"
    date: 2026-09-24
    author: Amish Chadha
    change: Initial draft
---
```

Quote version numbers so YAML keeps `1.0` as text instead of turning it into a number. List revisions newest last.

## 4. Writing style

- Chicago Manual of Style.
- No em dashes. Restructure the sentence instead.
- Lead each section with its conclusion, then support it.
- SI units throughout, in the form `12 kW`, `450 °C`, `3.2 m`. Imperial values may follow in parentheses.
- Number every figure and table ("Figure 2", "Table 1") and give each a caption.
- State every assumption in the calculation that depends on it.
- Put safety notes in a blockquote starting with **Safety:**.

## 5. Visual identity

| Element | Specification |
| --- | --- |
| Typeface | IBM Plex Sans for text, IBM Plex Mono for code and values (SIL Open Font License, bundled in `.kit/fonts`) |
| Ink | `#111827` |
| Secondary text | `#4B5563` |
| Rules and grid | `#D1D5DB` |
| Accent (one only) | `#0F766E` teal |
| Document page | US Letter, 20 mm margins |
| Drawing sheet | ANSI B landscape (431.8 x 279.4 mm) |
| Footer | Document ID, version, status, license and designmolecule.com on every page |

## 6. Drawing and sketch conventions

- Units are millimeters unless the title block says otherwise.
- Third-angle projection, marked with the symbol in the title block.
- Line weights: visible outlines 0.5 mm, hidden lines 0.25 mm dashed, center lines 0.18 mm chain.
- The title block contains the project, title, drawing number, revision, scale, units, projection, sheet, author, date, material or notes, and license.
- Every sheet and every render names the project and its GitHub repository (from `repo:` in `project.yaml`), at the top of the sheet and in the title block, so a printed or forwarded sheet is never anonymous.
- The drawing title names the device, not only the drawing type (for example "Handheld near-infrared resin scanner: general arrangement").
- Every view label states its scale and viewing direction (for example "Scale 1:1; side elevation looking along +Y"), and every isometric or render states where it is seen from.
- Orthographic views generated with `add_ortho` carry overall dimensions (length and depth on the top view, height on the front view) and ISO 128 centre lines on cylinders; hidden lines are dashed. Tolerances are not shown before TRL 4.
- Sheets are exported as SVG, PDF and a 300 dpi PNG.
- The revision table in the top right of the sheet lists every revision.
- Concept sketches use the same sheet and title block and carry the label "CONCEPT, NOT FOR FABRICATION".
- Geometry comes from `cad/src/*.py` (build123d). Sheets are generated by `.kit/drawing.py` and never edited by hand.

## 7. Project codes

| Code | Project | Code | Project | Code | Project |
| --- | --- | --- | --- | --- | --- |
| TBK | ThermaBrick | PCF | PicoFlow | HLT | HelioLite |
| CCB | CharCube | DRN | DustRunner | TRT | TremorTrace |
| STC | StepCue | FXH | FlexHand | CPD | ColdPod |
| SCL | SunClave | STR | SteamRoot | GGD | GrainGuard |
| SDL | SeedLine | ZBX | ZeerBox | RMS | RootMesh |
| DWD | DewDrive | SSK | StillStack | PPR | PotPress |
| WWT | WaterWatch | LMF | LumaFlow | FCL | FieldCell |
| CNP | ConePro | CVC | CulvertCrawl | EGD | EmberGuard |
| SNF | SnapFrame | CGM | CargoMule | SCM | StepClimber |
| SWC | SwapCell | PLP | PalletPilot | FTK | FlatTrike |
| WWK | WaterWalker | GRR | GrowRider | SSP | SunSpoke |
| SGN | StepGen | PBX | PowerBox | WML | WasteWise-ml |
| WSC | WasteWise Scan | RFE | ReflowEconomy | | |
| OHP | Portfolio-wide | | | | |

## 8. Build and publish

- `python .kit/render.py` checks every controlled document and renders it to `docs/pdf/<doc_id>_v<version>.pdf`.
- `python .kit/drawing.py` (called from each project's `cad/src/sheets.py`) builds drawing sheets as SVG and PDF in `cad/drawings/`.
- The GitHub Action in `.github/workflows/docs.yml` runs the checks on every push and attaches PDFs to a GitHub Release whenever a release tag is pushed.
- Public releases follow section 14: `python .kit/release_gate.py` must pass, and the release tag is `v0.<TRL>.0` (for example `v0.3.0` at TRL 3).

## 9. Technology Readiness Level (TRL)

Each project states its maturity as a Technology Readiness Level on the NASA and US DOE 1 to 9 scale. The TRL rates this specific design, not the underlying technology. A sand battery is commercial elsewhere, but a new sand battery design starts at TRL 2 until evidence shows otherwise.

| TRL | Definition | Evidence the repo must contain |
| --- | --- | --- |
| 1 | Basic principles observed | Problem statement (PRB) |
| 2 | Technology concept formulated | Draft precis (PRC) and requirements (REQ) |
| 3 | Analytical or experimental proof of concept | Calculation note (CAL), working build123d model with STEP export, drawing sheet (DWG), priced BOM with every unit cost filled in, prototype build plan (BLD) with pictures, `design_state: constructable` |
| 4 | Components validated in the lab | Test report (TST) with `environment: lab`, build log entries |
| 5 | Validated in a relevant environment | Test report (TST) with `environment: relevant` |
| 6 | System prototype demonstrated in a relevant environment | Precis at version 1.0 or later with status Released, a drawing at a lettered revision (Rev A or later), and a system-level TST with `environment: relevant` |
| 7 to 9 | Operational demonstration through proven in service | Beyond portfolio scope; claim only with a named deployment partner and evidence |

Rules:

- `project.yaml` records `trl` (current level), `trl_target` (the level the current effort aims for) and `trl_evidence` (the files that support the claim).
- `python .kit/render.py --check` fails if the evidence for the claimed TRL is missing. CI runs this check on every push.
- Documentation alone cannot go past TRL 3. TRL 4 and above require hardware and a test report.
- TRL and visibility are independent. A repo can be public at TRL 3 as a documented design ready to build.
- A change of TRL is recorded in the build log with the date and the evidence that justified it.

## 10. Portfolio phase and TRL cap

`.kit/PHASE.yaml` sets the current phase. During the **populate** phase every repo is capped at **TRL 3**: `trl` and `trl_target` may not exceed 3, and the check fails if they do. Every repo targets the cap: `trl_target` must equal 3, so a new repo is taken all the way to TRL 3 (scaffold, populate and advance, see `/to-trl3`). Work that belongs to TRL 4 or later (building or testing hardware, test articles, test plans and reports, build-log entries, purchasing lists, PCB layouts) must not be started. The prototype build plan (BLD, section 18) is TRL 3 paper work and is required. Where it already exists it is kept, flagged in the check output, and not extended. Only Amish changes `PHASE.yaml`.

Every repo carries a `CLAUDE.md` with the working rules for AI sessions: the TRL cap, decision rights (nothing is recorded as decided unless Amish decided it), one step per session, and a mandatory `docs/REVIEW.md` before stopping.

## 11. Concept media

Every repo at TRL 2 or above explains its idea visually. Media are generated from a build123d massing model with `.kit/concept.py`, never drawn by hand, so they stay in step with the design.

| File | Required | Purpose |
| --- | --- | --- |
| `media/hero.png` | TRL 2+ | Shaded isometric render with a 1.75 m person for scale; the website card image |
| `media/concept-blueprint.png` and `.pdf` | TRL 2+ | Blueprint concept sheet: orthographic and isometric views, scale, key figures, title block |
| `media/model.glb` and `media/viewer.html` | TRL 2+ | Interactive 3D viewer (glTF plus model-viewer) for the website |
| `media/cutaway.png` | When the inside matters | Section view showing internal parts |
| `media/exploded.png` | Recommended | Exploded view with numbered callouts matching the BOM |
| `media/flow.png` | When energy or material moves | System, energy or material flow diagram with losses |

Session commands in `.claude/commands/` (`/populate`, `/advance-trl3`, `/rein-in`, `/refresh-media`) carry the standard prompts, so every Claude Code session starts from the same instructions.

At TRL 2 a massing model is enough: correct overall proportions and main components. All concept media carry "CONCEPT, NOT FOR FABRICATION". The check warns when required media are missing at TRL 2 and fails at TRL 3.

## 12. Product renders

Every repo at TRL 3 shows the product as it would look, not only as a massing model.

- `cad/src/product_model.py` is the appearance model. It defines `product_parts()` (named parts with a shape and a material), `TITLE` ("Name: what it is") and `RENDER_VIEWS`. It is for renders only: every main dimension comes from `cad/src/model.py`, never typed in again.
- Where the appearance model departs from `model.py` (a chamfer, a label, a fastener drawn for realism), record the deviation in `docs/REVIEW.md` as "Proposed, awaiting Amish".
- Scale comes from context, not from a floating figure: a hand or forearm for handheld objects, and the posed mannequin (`mannequin()` in `.kit/context_parts.py`: stand, walk, push, ride, sit, reach) for anything a person uses at body scale.
- Renders are made with `.kit/export_views.py` (one scene per view) and `.kit/photoreal.py` (Blender Cycles), then captioned with `.kit/photo_caption.py`. Files are `media/render-<view>.png`; `media/render-hero.png` is required.
- Every caption names the project, the repository and the viewing direction, and carries "CONCEPT, NOT FOR FABRICATION".
- Captions never sit on the render. `.kit/photo_caption.py` adds a header band (title, concept label, repository) above the render and a footer band (view note) below it, wraps every line to the image width, and steps the font down to a floor before adding a line.
- The README opens with `media/render-hero.png`.
- Software-only and scene repositories (no single product) may use a scene render as the hero instead of a product model.

## 13. Storefront images

Two images, both made from `media/render-hero.png` by `python .kit/cards.py .`:

| File | Size | Purpose |
| --- | --- | --- |
| `media/card.png` | 800 x 800 | Square thumbnail for the organization profile page |
| `media/social-preview.png` | 1280 x 640, under 1 MB | GitHub social preview, shown when a repository link is shared |

- The social preview shows the area, name, one-line description, the first sentence of the pitch, the brand line and the repository address. Design Molecule repos read "Design Molecule · open hardware concept, TRL n"; OpenRatio repos read "OpenRatio · research and educational prototype, TRL n".
- GitHub has no API for the social preview. Upload it under the repository's Settings, Social preview, on release day.
- Regenerate both images whenever `render-hero.png` changes.

### Image quality

Every render, card and social preview must be clear and readable. `python .kit/image_qc.py` checks each one, and the release gate blocks on any failure:

| Check | Rule |
| --- | --- |
| Layout | Made by the current `photo_caption.py` or `cards.py`, which store the text layout in the PNG |
| Text inside the image | Every line at least 1.2 % of the image width from each edge; nothing runs off the side |
| No overlap | No line of text touches another line, and no caption text sits on the render |
| Text size | Render captions at least 1.05 % of the image width in pixel height (17 px at 1600 px); social preview text at least 16 px |
| Resolution | Renders at least 1200 px wide; card 800 x 800; social preview 1280 x 640 and under 1 MB |
| Sharpness | The render is not blurred or upscaled (edge sharpness at least 15 on the `image_qc.py` scale) |

Long titles and notes wrap to more lines rather than shrinking below the floor. The social preview shortens the pitch sentence with an ellipsis only if it cannot fit at the smallest size.

## 14. Public release

A repository goes public only when Amish approves it, and only after `python .kit/release_gate.py` passes. The gate checks:

1. `render.py --check` passes (document control, TRL cap, concept media).
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

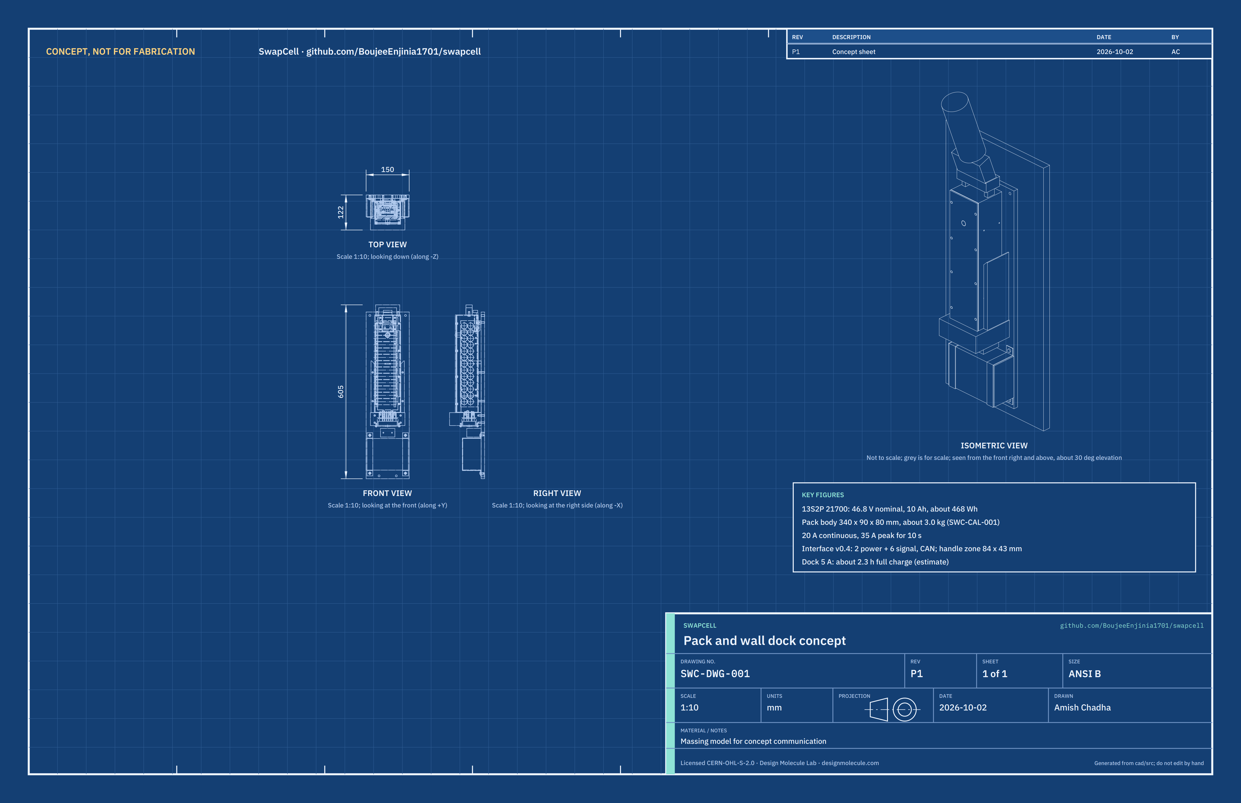
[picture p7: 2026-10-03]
media/concept-blueprint.png

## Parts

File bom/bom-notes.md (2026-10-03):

# BOM notes

Every line in `bom/bom.csv` is priced (TRL 3). Prices are estimates for one-off purchase in 2026 US dollars, with a supplier or supplier type; they are not quotes. Item numbers 1 to 11 match the exploded view (`media/exploded.png`), the components table in SWC-PRC-001 and drawing SWC-DWG-002; the build plan SWC-BLD-001 shows every made item. The totals below are printed by `docs/04-calcs/sizing.py` (SWC-CAL-001).

| Group | Items | Cost |
| --- | --- | --- |
| One pack | 1 to 7, 12 to 16 | USD 449 (cells USD 143) |
| One wall dock | 8 to 11, 17 | USD 170 |
| Total | 1 to 17 | USD 619 |

Value-engineering target: USD 700 (`budget_usd` in `project.yaml`, a hypothetical control target, not a limit). Estimated cost of the constructable design: USD 619 (USD 81 under the target). Changes since TRL 2: cell price raised from USD 4.50 to USD 5.50 for a named-brand high-power cell from an authorized distributor, latch pawl and tray upgraded for the class V1 proof load, and item 14 (wake button, interface v0.3) added. Making the design constructable on 2026-10-01 (SWC-DDR-003) added USD 47: lines 15 (latch housing, release slider and springs), 16 (cell holder frames, moved out of line 12) and 17 (dock mounting parts), a longer back plate on line 8, front flanges on the tray (line 1) and more fixings (line 13). Every line now has geometry in the model except line 12 (wiring) and the label on line 14.

**Shared packs.** By Amish's 2026-09-25 portfolio rule, the SwapCell pack is priced here only. Dependent kits (PowerBox, SunSpoke, StepGen, WaterWalker, CargoMule and others) exclude it from their budgets and cite this BOM.

A second pack for a real swap demonstration would add about USD 449 (total about USD 1,068). Amish decided on 2026-09-25 (SWC-DDR-002) that this build budget is set before any build; it is on hold with TRL 4.

Cells must be new, matched and bought from an authorized distributor. Do not substitute recycled or unknown-grade cells in the reference pack.

Decisions of 2026-10-02 (SWC-DEC-001): the prototype lid (line 4) is cut from 3 mm UL 94 V-0 polycarbonate sheet rather than printed; line 4 now names the sheet, bought cut to size from a plastics distributor, at an estimated USD 25 (was USD 12 for printing filament), which adds USD 13; the large-format printer note is dropped. The state-of-charge light bar is an optional pack feature under line 14 and the dock status light sits under line 11; neither is in the prototype's quantities. No other quantity or price changed.

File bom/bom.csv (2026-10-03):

item | qty | spec | supplier | unit_cost_usd | make_buy | notes
1 Pack housing tray | 1 | Folded 1.5 mm 5052 aluminium: back, two sides and two ends from one blank with riveted corner tabs, 8 mm inward flanges round the open front, holes and slots per SWC-DWG-101; flame-retardant liner | Local sheet-metal shop or online sheet-metal service | 35.00 | make | Estimate for one-off folding; about 0.43 kg; flanges added for the lid fixing (SWC-DDR-003)
2 Lithium-ion cell | 26 | 21700, 5.0 Ah nominal (4.85 Ah minimum), 3.6 V, 25 A or more continuous; 13S2P; new and matched | Authorized cell distributor | 5.50 | buy | Small-quantity estimate; model chosen at supplier selection
3 BMS board with CAN | 1 | Open-source 13S BMS, CAN 2.0B, balancing, 30 A FETs, pre-charge, flash log, sleep current 100 uA or less, INTERLOCK wake comparator | Open-source BMS project or electronics distributor (assembled board) | 120.00 | buy | Estimate; must support interface v0.4 wake and charge-discharge mode
4 Pack lid | 1 | 3 mm UL 94 V-0 polycarbonate sheet, cut 90 x 340 mm, 8 countersunk screw holes and the wake button hole drilled; seals on a flat gasket (line 13) | Plastics distributor (flame-retardant polycarbonate sheet cut to size) | 25.00 | make | Estimate: one cut-to-size piece of 3 mm UL 94 V-0 polycarbonate (about 0.03 m²) with a one-off cutting charge, drilled and countersunk by hand; decided 2026-10-02 (SWC-DEC-001)
5 Blind-mate plug, pack side | 1 | Printed keyed shroud with 2 x 40 A power socket contacts and 6 potted signal socket contacts, sequenced lengths; four M3 screws from inside the tray into heat-set inserts | Connector distributor (contacts) and self (shroud) | 30.00 | buy | Estimate; connector family decided 2026-09-25 (SWC-DDR-002); contact parts chosen at supplier selection
6 Carry handle | 1 | Printed loop, 84 x 22 x 35 mm, 25 mm grip clearance; two M5 screws from inside the tray into heat-set inserts in its legs | Self | 6.00 | make | Material cost only
7 Latch pawl | 1 | Steel pawl 36 mm wide, 24 mm tooth height, 4 mm engagement under the dock catch, 10 mm shoulder with a 45 degree release ramp; proof load 1.72 kN (class V1) | Self and hardware store (spring steel and spring) | 12.00 | make | Estimate; sized in SWC-CAL-001; released by line 15 (SWC-DDR-003)
8 Wall dock cradle | 1 | 12 mm aluminium back plate 150 x 580 mm, printed cradle shelf and two side guides with heat-set inserts and 10 mm lead-ins, steel latch catch 50 x 8 x 12 mm | Self and local metal supplier | 40.00 | make | Material cost only; plate lengthened to carry the catch and charger straps (SWC-DDR-003)
9 Blind-mate receptacle, dock side | 1 | Printed receptacle shroud with a top flange and key post, 2 power and 6 signal pins, floating +/-3 mm under the shelf pocket ledge on a foam pad, 10 kOhm INTERLOCK coding resistor | Connector distributor (contacts) and self (mount) | 30.00 | buy | Estimate; replaceable wear part; retainer and foam on line 17
10 Dock charger | 1 | Certified 54.6 V 5 A CC-CV lithium-ion charger, 100 to 240 V AC input, adjustable to 53.3 V for fleet mode | Electronics distributor or e-bike parts supplier | 60.00 | buy | Estimate; certified unit only
11 Dock controller | 1 | ESP32 board, CAN transceiver, DC relay, current sensor, microSD, in a 50 x 50 x 30 mm ABS box screwed to the back plate | Electronics distributor | 25.00 | buy | Estimate
12 Fuses and pack wiring | 1 | 40 A main fuse, pre-charge resistor, fuse wire, nickel strip, 10 AWG silicone wire, fish paper, thermistors | Electronics distributor | 36.00 | buy | Estimate; not modelled; cell holders moved to line 16
13 Seals and hardware | 1 | 1 mm flat lid gasket, 8 x M3 press-in nuts and countersunk lid screws, M3 plug screws and M5 handle screws with heat-set inserts, 4 x M2.5 countersunk holder screws and inserts, BMS standoffs and screws, 6 x 4 mm countersunk blind rivets, foam, thermal pads | Hardware store | 20.00 | buy | Estimate; fixings added for construction (SWC-DDR-003)
14 Wake button and label | 1 | Sealed momentary switch (IP67 class) on the lid for manual wake, interface version label | Electronics distributor | 6.00 | buy | Estimate; interface wake item (v0.3 on); not modelled
15 Latch housing, release slider and springs | 1 | 1.5 mm steel sheet folded into an open box with two riveting flanges (the latch doubler); 5 x 30 mm steel bar release slider with a 45 degree ramp; printed thumb button; two compression springs 5 mm diameter | Self and hardware store | 10.00 | make | Estimate; added for construction (SWC-DDR-003)
16 Cell holder frames | 2 | Printed flame-retardant frames 6 mm thick with 26 cell pockets, bearing on the tray back wall, two M2.5 screws each | Self (filament from a 3D-printing supplier) | 3.00 | make | Material cost only; were part of line 12 (SWC-DDR-003)
17 Dock mounting parts | 1 | 3 mm aluminium receptacle retainer plate, 15 mm closed-cell foam pad, two 1.5 x 20 mm aluminium charger straps, M5 countersunk screws, heat-set inserts, M4 controller screws, four wall anchors | Self and hardware store | 15.00 | make | Estimate; added for construction (SWC-DDR-003)

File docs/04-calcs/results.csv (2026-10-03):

id | value | target | status
R1 | 46.8 V nominal, 39.0 to 54.6 V | 46.8 V; 39.0 to 54.6 V | Met
R2 | 10.0 Ah and 466 Wh nominal; 9.7 Ah and 452 Wh at cell minimum | 10 Ah and 450 Wh at 0.2C | At risk
R3 | 51 C base, 56 C with end-of-discharge R in open air; derates to 18.6 A enclosed and 14.0 A from 45 C; 17.5 A per cell at 35 A | Below 60 C from 25 C at 20 A in an open-air mount; derate elsewhere; 35 A for 10 s | Met (on paper)
R4 | 2.3 h full; 1.6 h to 80 % | 3 h full; 2 h to 80 % | Met
R5 | 3.03 kg | 3.5 kg or less | Met
R6 | 340 x 90 x 80 mm; 393 mm overall | 400 mm or less overall | Met
R7 | insertion about 41 N (assumed contact forces) | 10 s, one hand, 50 N or less | Not verifiable at TRL 3
R8 | Gasketed lid, potted pack-side contacts (design review only) | Pack IP65, dock IP54 | Not verifiable at TRL 3
R9 | 300 to 500 cycles typical; 4.1 V fleet mode adopted | 500 cycles to 80 %; SoH within 5 % | At risk
R10 | 3650 cycles in 5 years, margin 1.37x; custom keyed shroud, contacts not yet chosen | 5,000 cycles, +/-3 mm, +/-2 deg, 40 A | Not verifiable at TRL 3
R11 | Short circuit 496 A; pre-charge 460 ms; functions specified | Protections listed in R11 | Not verifiable at TRL 3
R12 | Bus load 1.8 %; log 62.5 KiB, 10 s | CAN 250 kbit/s, 2,000 records, CSV export | Met (on paper)
R13 | Sleep drain 0.72 %/month; coded INTERLOCK 0.30 V window | Wake with no host supply; 1 %/month or less | Met (on paper)
R14 | Net 3.8 A charge in the PowerBox case, within 5.0 A | Charge-discharge mode within limits | Met (on paper)
R15 | Proof 1717 N; bearing margin 4.2x; lever ratio 6.6 | Class V1 vibration and shock, no release | Not verifiable at TRL 3
R16 | Pack and dock parts 619 USD, 81 USD under the target | Value-engineering target 700 USD for one pack and one dock | Under the target

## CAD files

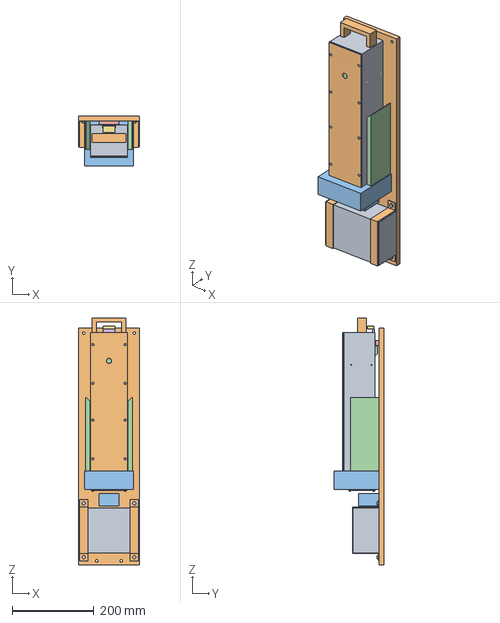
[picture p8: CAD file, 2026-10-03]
cad/step/swapcell-assembly.step
150.0 x 122.0 x 605.0 mm

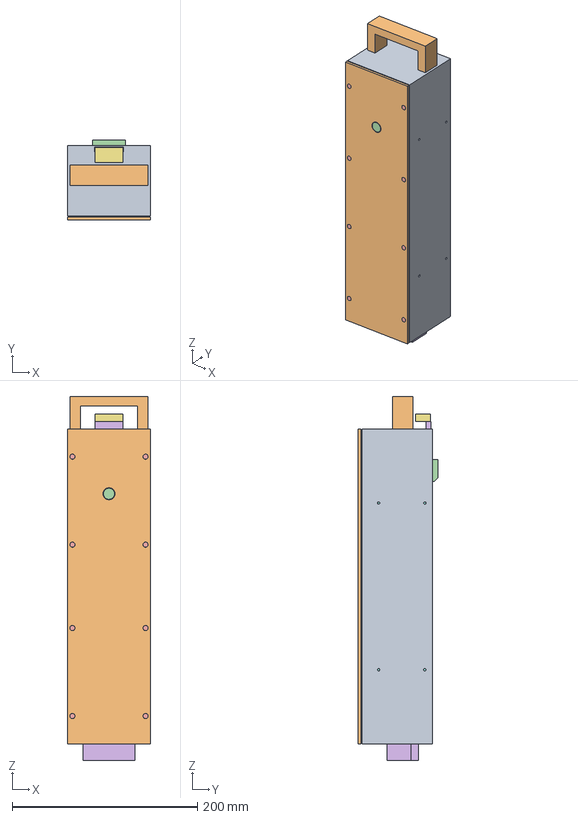
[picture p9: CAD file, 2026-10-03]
cad/step/swapcell-pack.step
90.0 x 86.0 x 393.0 mm

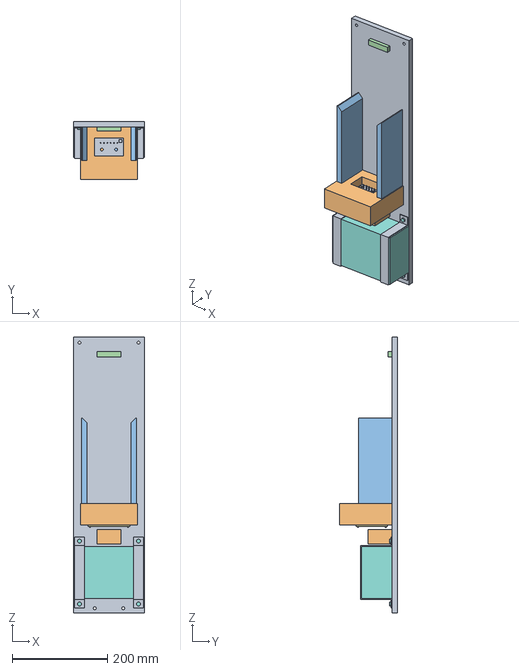
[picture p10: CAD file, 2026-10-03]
cad/step/swapcell-dock.step
150.0 x 122.0 x 580.0 mm

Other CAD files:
cad/stl/swapcell-assembly.stl
cad/stl/swapcell-dock.stl
cad/stl/swapcell-pack.stl

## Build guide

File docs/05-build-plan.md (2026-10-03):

---
doc_id: SWC-BLD-001
title: SwapCell prototype build plan
project: SwapCell
doc_type: Build plan
version: "0.3"
status: Draft
date: '2026-10-02'
author: Amish Chadha
license: CERN-OHL-S-2.0
revisions:
  - version: "0.1"
    date: '2026-10-01'
    author: Amish Chadha
    change: First build plan, with pictures by component and step; design made constructable (SWC-DDR-003)
  - version: "0.2"
    date: '2026-10-02'
    author: Amish Chadha
    change: "Decisions of 2026-10-02: lid cut from 3 mm UL 94 V-0 polycarbonate sheet; board temperature sensor on the rear row of cells. Pictures unchanged"
  - version: "0.3"
    date: '2026-10-02'
    author: Amish Chadha
    change: "Approved follow-ups carried out: wiring figure shows the board temperature sensor; lid and catch sketches revised (SWC-DWG-108 and 112 Rev P2); interface v0.4 catch sizes; cost USD 619"
---

# SwapCell prototype build plan

**Plan, not yet built.** How to build the first proof-of-concept prototype, one pack and one wall dock, component by component. Building and testing to it is TRL 4 work. Decisions still to be made are kept in the design decisions register ([docs/06-design-decisions.md](06-design-decisions.md)), not here.

## 1. What you are building

Figure 1. Every component, pulled apart and numbered in build order

*Figure 1. Every component pulled apart and numbered in build order: the pack (1 to 11) up and to the left, the wall dock (12 to 20) on the right.*

The prototype is one SwapCell pack and one wall dock. The pack is a folded aluminium box, 340 x 90 x 80 mm, holding 26 lithium-ion cells in two printed frames and a battery management board, closed by a lid on a gasket, with a carry handle on top, a keyed plug underneath and a spring latch on its back. The dock is a 12 mm aluminium plate on the wall carrying a printed shelf and two printed guides that the pack drops between, a floating receptacle in the shelf, a steel catch for the latch, a controller box and a bought, certified charger. Figure 1 shows the 20 components in the order you make or fit them. Fourteen are made in a small workshop: the tray, latch housing, latch pawl, release slider and button, plug shroud, cell holder frames, handle and lid of the pack; the back plate, shelf, guides, catch, receptacle shroud, retainer plate and charger straps of the dock. The cells, the battery management board, the contacts, the charger, the controller and the fixings are bought. The work is folding and drilling aluminium sheet, cutting and drilling plate and steel bar, filing, 3D printing, fitting heat-set inserts, spot welding nickel strip, and wiring at block level. The parts cost about USD 619 from the bill of materials.

> **Safety:** The pack stores about 468 Wh in lithium-ion cells at up to 54.6 V and can deliver about 500 A into a short. A cell in thermal runaway vents flammable, toxic gas and can set its neighbours alight. Build, charge and test the pack only inside a fireproof enclosure on a non-combustible surface, with a lithium-rated or Class D extinguisher and a bucket of sand at hand, and never leave it unattended. Use insulated tools, keep the battery management board unplugged until section 6 says otherwise, and stop at every safety stop in section 6. The dock charger plugs into a mains socket; no mains wiring is part of this build.

## 2. What changed to make it buildable

The concept showed what SwapCell does and fixed its published interface; many of its parts had no fixing, and the latch could not work as drawn. Each change below keeps what the pack and dock do and keeps every published interface size. All of them are recorded in decision record SWC-DDR-003, open for Amish's review.

*Table 1. Changes from the concept.*

| Component | The concept had | The buildable design has | Why |
| --- | --- | --- | --- |
| Latch catch | A catch 2 mm below the pawl, which could never stop the pack being lifted out | A steel catch 1 mm above the pawl, which the pawl hooks 4 mm under (Figure 21) | A spring latch must pass the catch on the way in and hook under it |
| Latch pawl | A block 10 mm proud with no room to retract and no release | A pawl 6 mm proud that slides in a riveted steel housing, pushed out by two springs and pulled in 5 mm by a ramped slider under a thumb button (Figure 5) | Nothing to pivot or pin; the housing is the doubler the latch sizing assumed |
| Cells | 1 mm from the back wall | 8 mm further toward the lid, held in two printed frames that rest on the back wall (Figure 11) | Room for the latch; the cells now have a fixing |
| Lid | A plate on the 1.5 mm edges of the tray, with no fixing | Eight screws into press-in nuts in 8 mm flanges folded into the tray's front, over a 1 mm gasket (Figure 3) | A sealing face and something to screw into; the tray is 1 mm shallower so the body stays 80 mm deep |
| Plug, handle, cell frames, battery management board | No fixings | Screws from inside the tray into heat-set inserts, or countersunk from outside so the faces stay flat (Figures 9, 14) | The published faces stay flush |
| Receptacle | Drawn inside the solid shelf, unable to float | Held in a cavity under the shelf pocket by its flange, on a foam pad, free to float 3 mm each way (Figure 23) | The connector needs that float to line up |
| Guides, shelf, catch, controller box, charger | Floating off the back plate or past its edge, or with no fixing | All screwed to the back plate; the plate is 580 mm tall (was 520) to carry the catch and two charger straps (Figures 18, 26) | Each part can be made and replaced on its own |

## 3. Making the components

Make and check each component before the assembly step that needs it. Sizes are in millimetres. "Left" and "right" are as seen standing in front of the pack, looking at its lid; "back" is the face toward the wall; "up" is measured from the connector face, the pack's underside. Workshop tolerance is 0.5 mm unless a step says otherwise; drawings do not carry tolerances before TRL 4.

### 3.1 Pack tray

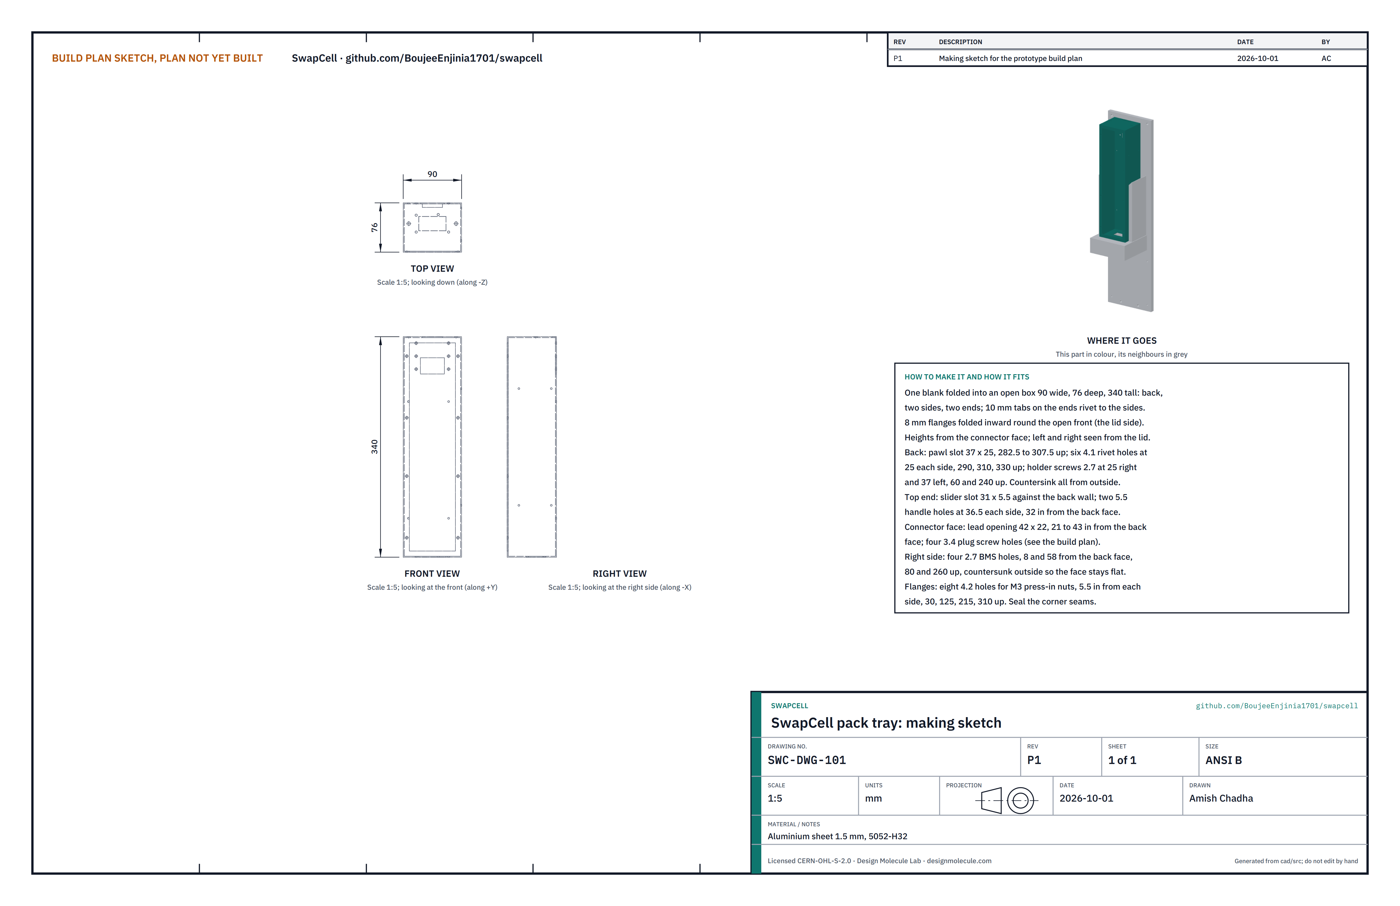
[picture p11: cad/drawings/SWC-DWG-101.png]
Figure 2. Making sketch of the pack tray


*Figure 2. Pack tray making sketch (SWC-DWG-101).*

**What it is and what it is made from.** The aluminium box that is the pack's body: its back, two sides and two ends are the published guide, latch and connector faces. Aluminium sheet 1.5 mm, 5052-H32, folded from one blank. A sheet-metal shop can cut and fold it from the sketch; the steps below are for doing it yourself.

**How to make it.**

1. Lay out the blank: the back, 90 wide x 340 tall, in the middle; a side 76 wide on each long edge; an end 76 deep on each short edge, with a 10 mm tab on each end of it; an 8 mm flange along the free edge of each side and each end. Drill a 3 mm relief hole wherever two fold lines cross.
2. Mark and drill every hole while the blank is flat (the sketch gives every position):
   - back: a pawl slot 37 wide x 25 tall, centred across, 282.5 to 307.5 up; six 4.1 mm rivet holes, 25 each side of centre, 290, 310 and 330 up; four 2.7 mm holder screw holes, 25 right and 37 left of centre, 60 and 240 up;
   - top end: a slot 31 x 5.5 against the back wall, centred across, for the release slider; two 5.5 mm holes 36.5 each side of centre, 32 in from the back face, for the handle screws;
   - connector face: a lead opening 42 x 22, centred across, 21 to 43 in from the back face; four 3.4 mm plug screw holes, two 25 each side of centre 45 in from the back face, one 25 left of centre 19 in, one 9 right of centre 18 in;
   - right side: four 2.7 mm holes 8 and 58 in from the back face, 80 and 260 up, for the battery management board;
   - flanges: eight 4.2 mm holes for the press-in nuts, 5.5 in from the outside of each side wall, 30, 125, 215 and 310 up.
3. Countersink every hole in the back and the right side from the outside so screw and rivet heads sit flush: these are published faces and nothing may stand out of them. Cut the slots by chain drilling and filing square.
4. Fold the flanges inward 90 degrees first, then the sides and ends up 90 degrees, then the tabs onto the sides. Rivet each tab with two 3.2 mm blind rivets and seal each corner seam inside with a bead of neutral-cure silicone.
5. Press the eight M3 press-in nuts into the flanges from inside, in a vice with soft jaws, until flush.
6. Deburr everything. Line the inside of the back, sides and ends with flame-retardant liner sheet, cut clear of every hole.

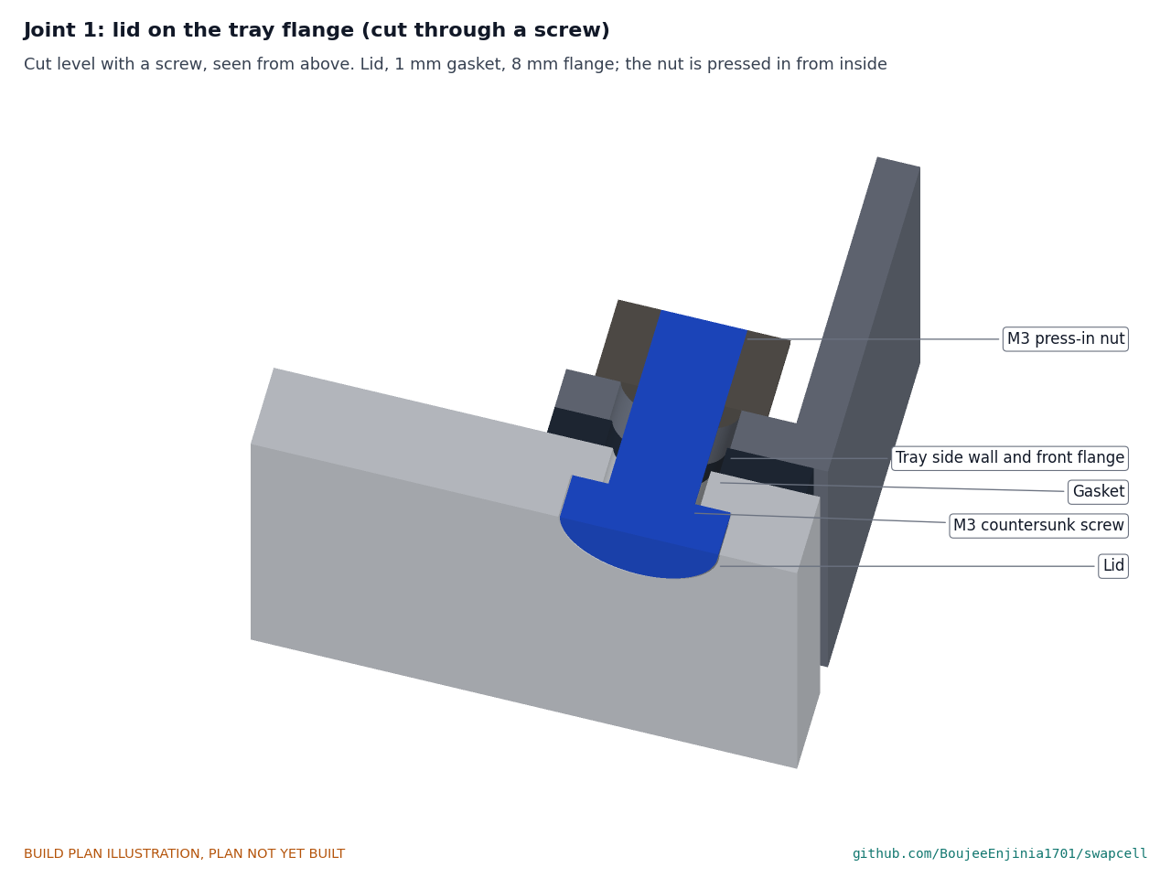
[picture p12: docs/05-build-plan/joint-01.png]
Figure 3. Joint 1: lid on the tray flange


*Figure 3. The lid sits on a 1 mm gasket on the 8 mm flange; a countersunk M3 screw goes into the press-in nut.*

**How it fits the parts next to it.** The lid closes the open front over the flanges (Figure 3). The latch housing is riveted inside the back wall (Figure 5), the plug shroud screws under the connector face (Figure 12), the cell frames rest on the inside of the back wall (Figure 11), the battery management board stands on the right side wall, and the handle screws onto the top end (Figure 14).

**Check before moving on.** Outside 90 wide, 80 deep with the lid on, 340 tall, within +0 and -1.5. Every corner square; no rivet or screw head stands proud of the back or sides; the eight nuts take an M3 screw by hand.

### 3.2 Latch housing

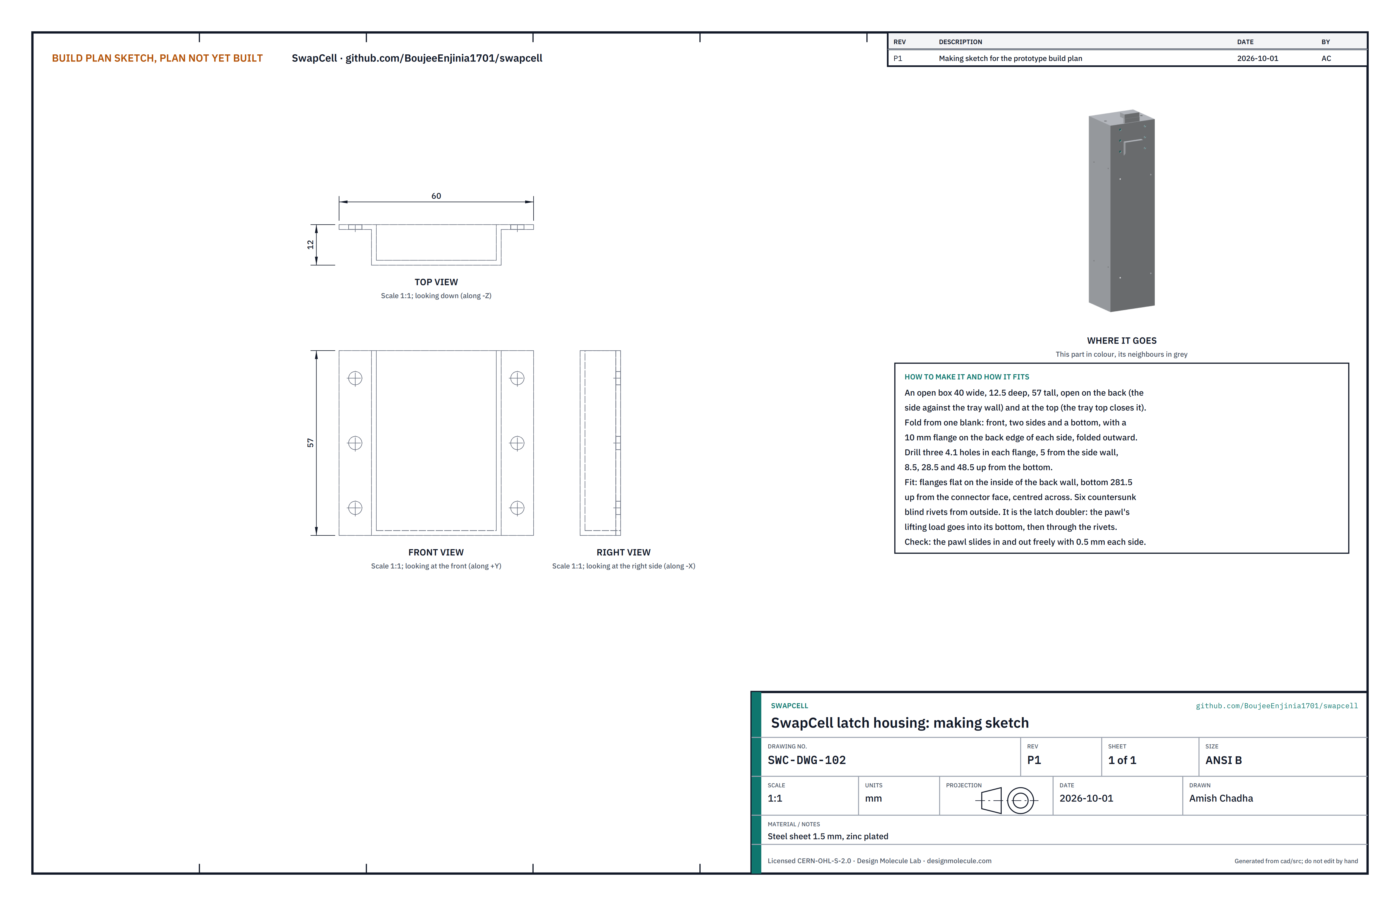
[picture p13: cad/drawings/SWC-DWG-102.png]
Figure 4. Making sketch of the latch housing


*Figure 4. Latch housing making sketch (SWC-DWG-102).*

**What it is and what it is made from.** A small open steel box riveted inside the back wall that guides the pawl and carries its load into the tray. Zinc-plated steel sheet 1.5 mm.

**How to make it.**

1. Cut a blank for an open box 40 wide, 12.5 deep and 57 tall: a front 40 x 57, two sides 12.5 x 57, a bottom 40 x 12.5, and a 10 mm flange on the back edge of each side.
2. Fold the sides and bottom toward the back, then the flanges outward, square.
3. Drill three 4.1 mm holes in each flange, 5 from the side wall, 8.5, 28.5 and 48.5 up from the bottom.

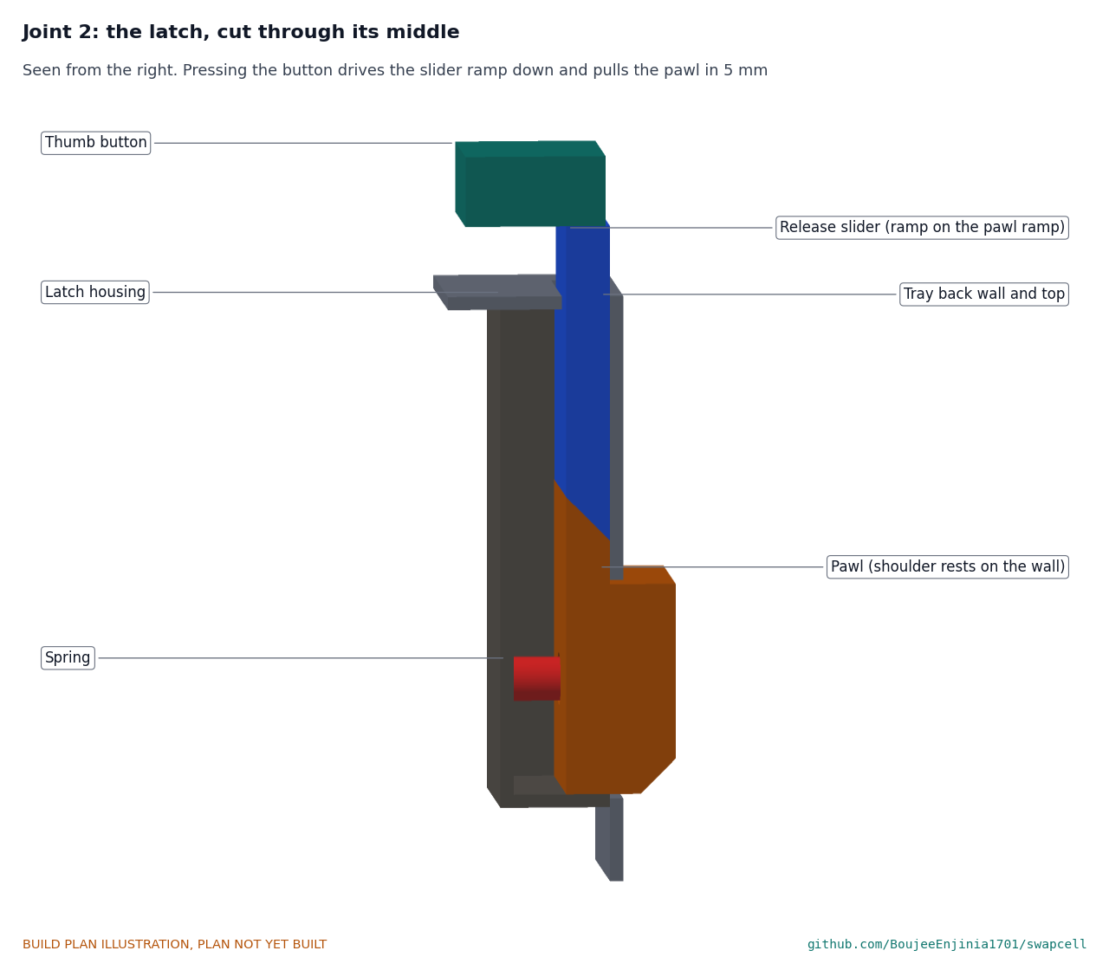
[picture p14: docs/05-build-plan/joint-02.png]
Figure 5. Joint 2: the latch, cut through its middle


*Figure 5. The pawl's shoulder rests on the back wall; the slider's ramp sits on the pawl's ramp. Pressing the button pushes the slider down and pulls the pawl in.*

**How it fits the parts next to it.** The flanges lie flat on the inside of the back wall, the bottom 281.5 up, centred across, over the pawl slot; six countersunk blind rivets go in from outside. The housing's top is open and stops just under the tray's top end. The pawl slides inside it with 0.5 mm each side, and its springs push against the housing's front.

**Check before moving on.** The pawl slides in and out of the housing freely by hand.

### 3.3 Latch pawl

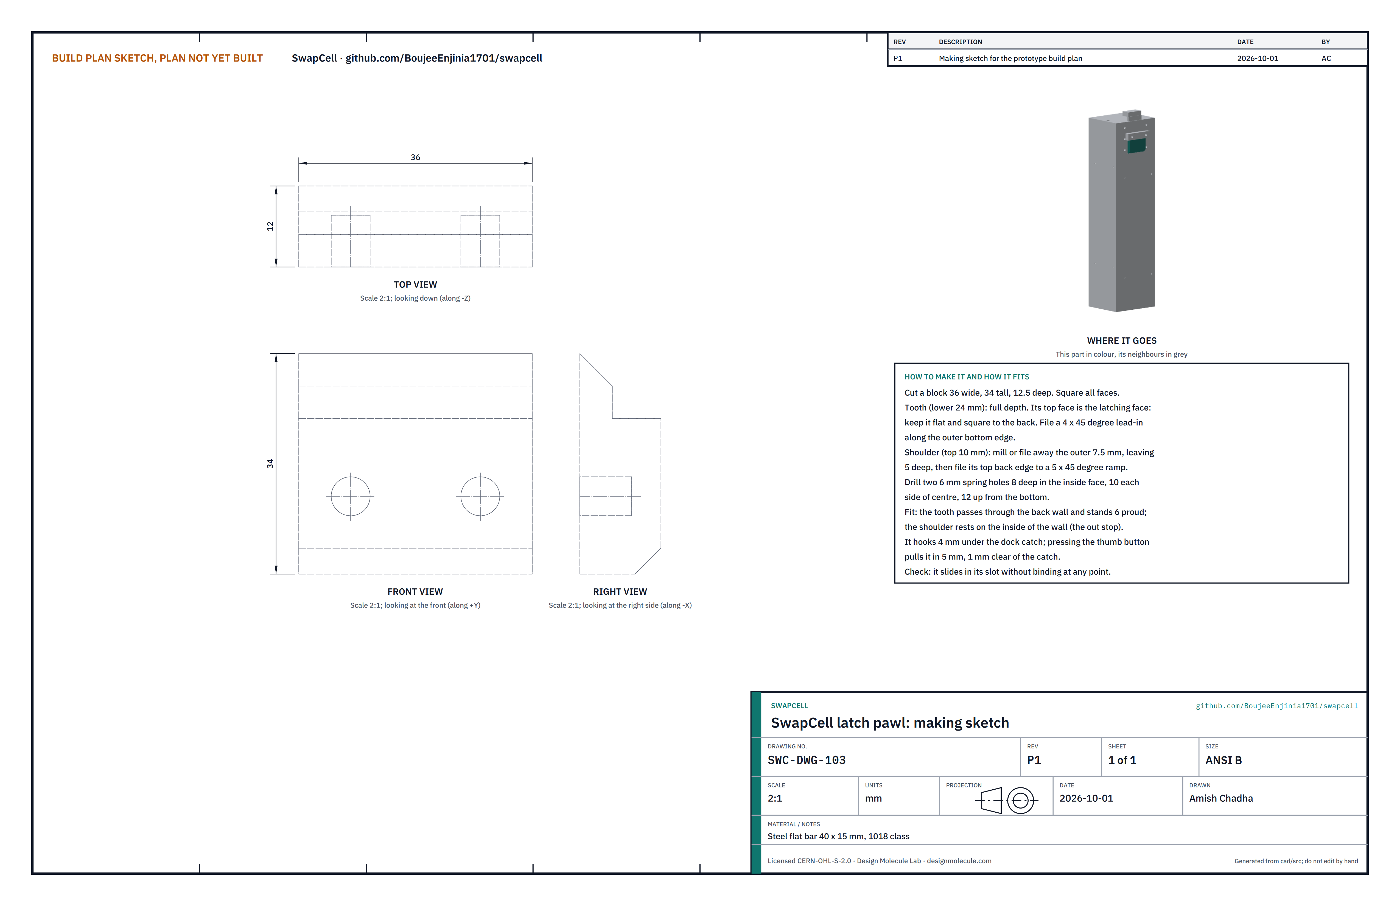
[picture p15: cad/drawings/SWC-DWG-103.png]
Figure 6. Making sketch of the latch pawl


*Figure 6. Latch pawl making sketch (SWC-DWG-103).*

**What it is and what it is made from.** The steel tooth that stands out of the back face and hooks under the dock's catch. Steel flat bar 40 x 15 mm, 1018 class.

**How to make it.**

1. Cut a block 36 wide, 34 tall and 12.5 deep; square all faces.
2. The lower 24 mm is the tooth, full depth. Its top face is the latching face: keep it flat and square to the back. File a 4 mm x 45 degree lead-in along its outer bottom edge, so the catch pushes it in as the pack drops.
3. The upper 10 mm is the shoulder. Mill or file away its outer 7.5 mm, leaving 5 mm deep, then file its top back edge to a 5 mm x 45 degree ramp.
4. Drill two 6 mm spring holes 8 deep in the inside face, 10 each side of centre, 12 up from the bottom.

**How it fits the parts next to it.** The tooth passes out through the slot in the back wall and stands 6 mm proud of the back face; the shoulder rests on the inside of the wall above the slot, which stops it coming further out. In the dock it sits 1 mm below the catch and overlaps it by 4 mm (Figure 21). Pressing the thumb button pulls it in 5 mm, 1 mm clear of the catch.

**Check before moving on.** It slides in its slot without binding at any point; the latching face is flat.

### 3.4 Release slider and thumb button

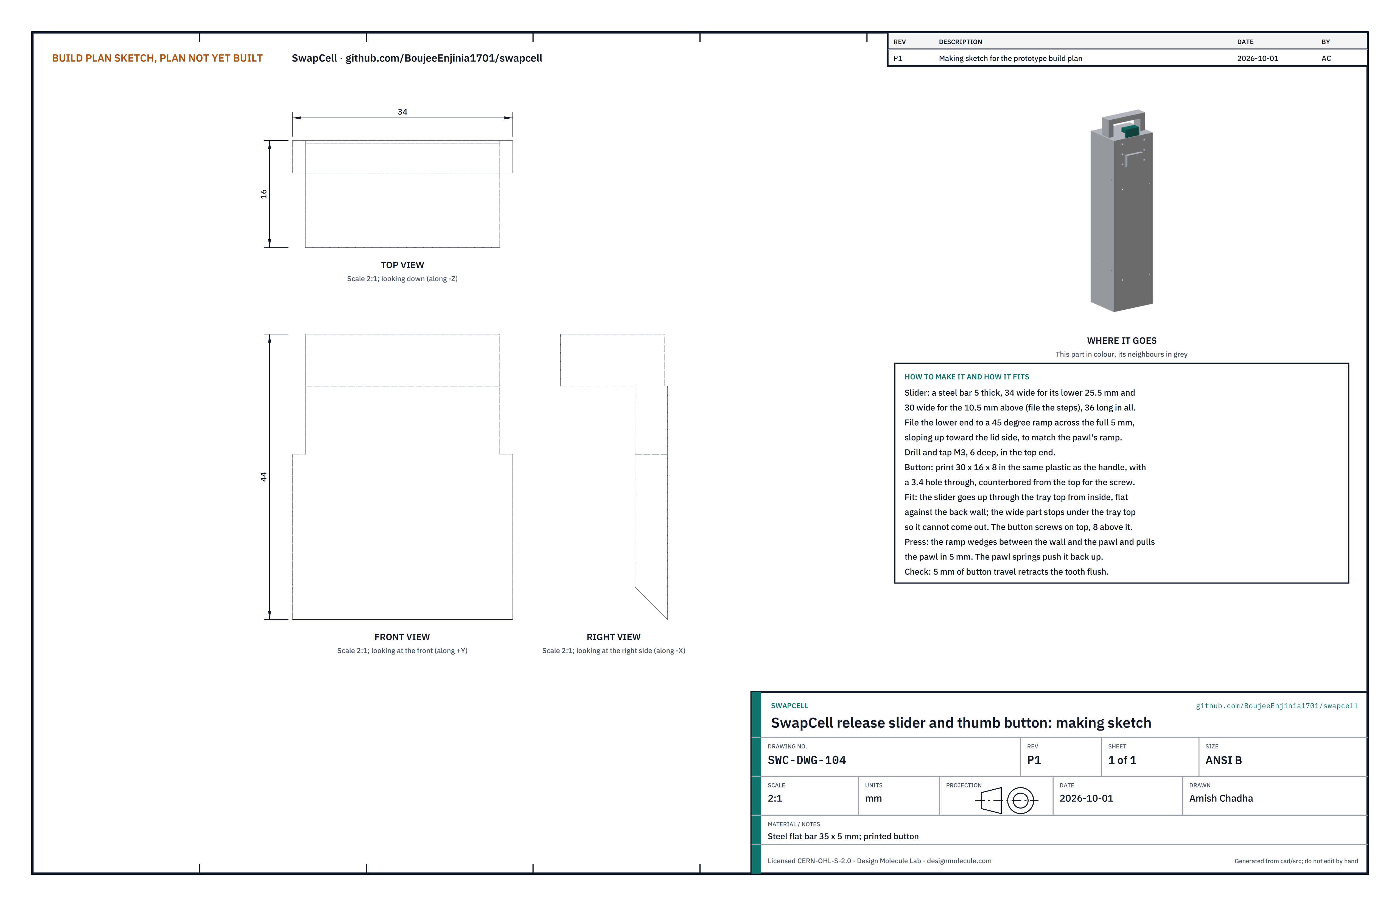
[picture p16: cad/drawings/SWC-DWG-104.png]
Figure 7. Making sketch of the release slider and thumb button


*Figure 7. Release slider and thumb button making sketch (SWC-DWG-104).*

**What it is and what it is made from.** A steel bar that runs down the inside of the back wall from a button on the top end; its ramped lower end pulls the pawl in. Steel flat bar 35 x 5 mm; button printed in the same plastic as the handle.

**How to make it.**

1. Cut the bar 36 long. File it 34 wide for its lower 25.5 mm and 30 wide for the 10.5 mm above, so the wide part cannot pass up through the slot in the tray top.
2. File the lower end to a 45 degree ramp across the full 5 mm thickness, sloping up toward the lid, to match the pawl's ramp.
3. Drill and tap M3, 6 deep, in the top end.
4. Print the button 30 x 16 x 8 with a 3.4 mm hole through, counterbored from the top for the screw head.

**How it fits the parts next to it.** The slider goes up through the slot in the tray top from inside, flat against the back wall, its ramp on the pawl's ramp (Figure 5). The button screws onto its top and sits 8 mm above the tray, just behind the handle's grip. Pressed 5 mm, the slider wedges between the wall and the pawl and pulls the pawl in 5 mm; the pawl's springs push both back.

**Check before moving on.** With the housing fitted, 5 mm of button travel brings the tooth flush with the back face, and the button returns by itself.

### 3.5 Plug shroud

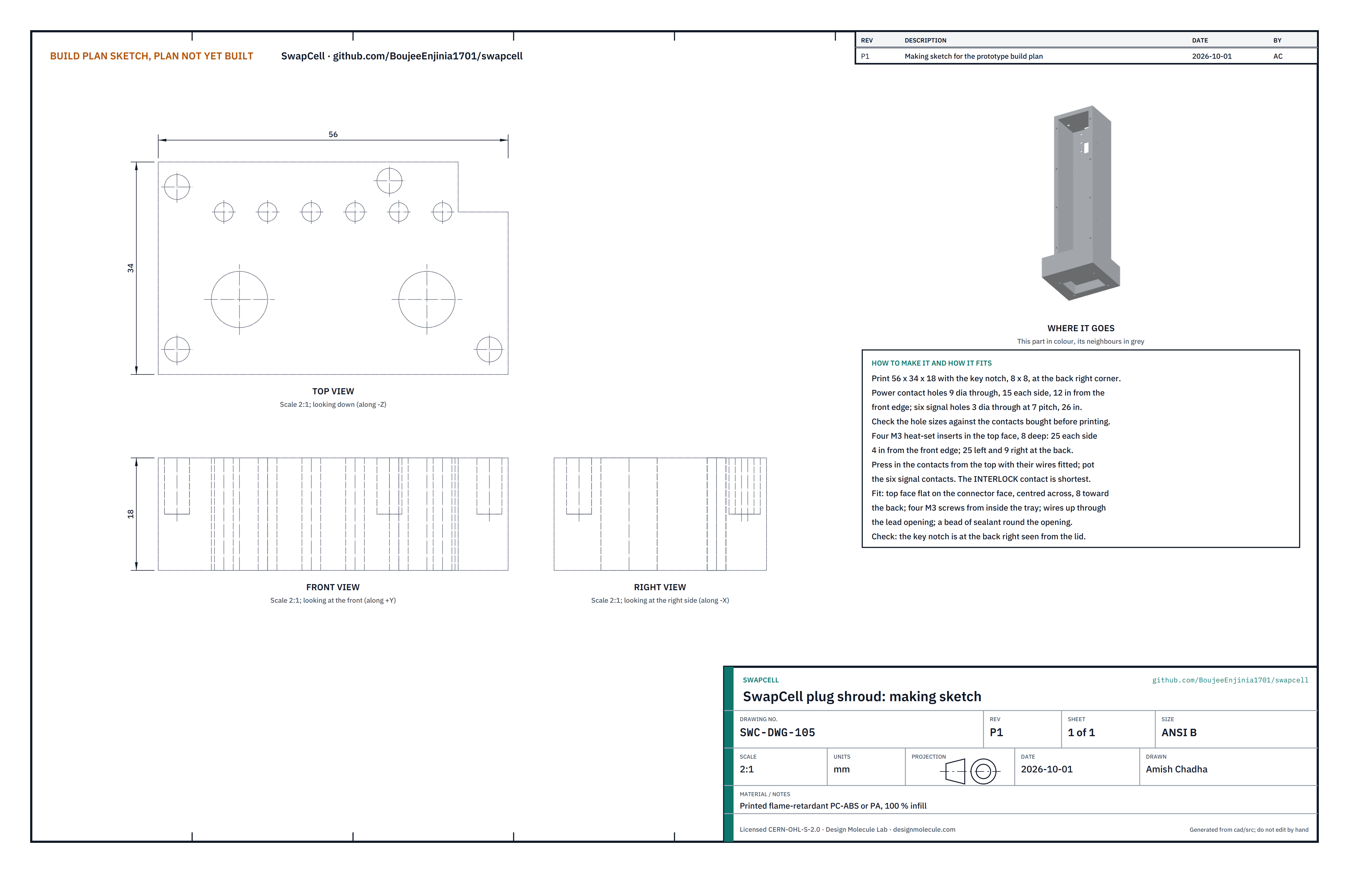
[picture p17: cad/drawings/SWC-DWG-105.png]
Figure 8. Making sketch of the plug shroud


*Figure 8. Plug shroud making sketch (SWC-DWG-105).*

**What it is and what it is made from.** The keyed block under the pack that carries the two power and six signal socket contacts. Printed in flame-retardant PC-ABS or nylon at 100 % infill; the contacts are bought.

**How to make it.**

1. Check the bought contacts' diameters and change the hole sizes on the sketch to suit before printing.
2. Print 56 x 34 x 18 with the key notch, 8 x 8, at its back right corner. Power contact holes 9 mm through, 15 each side of centre, 12 in from the front edge; six signal holes 3 mm through at 7 mm pitch, 26 in from the front edge.
3. Fit four M3 heat-set inserts in the top face, 8 deep, at the four screw positions of the sketch.
4. Crimp the power leads and signal wires to the contacts, then press the contacts in from the top. The INTERLOCK contact is the shortest so it mates last. Pot the six signal contacts with flame-retardant epoxy.

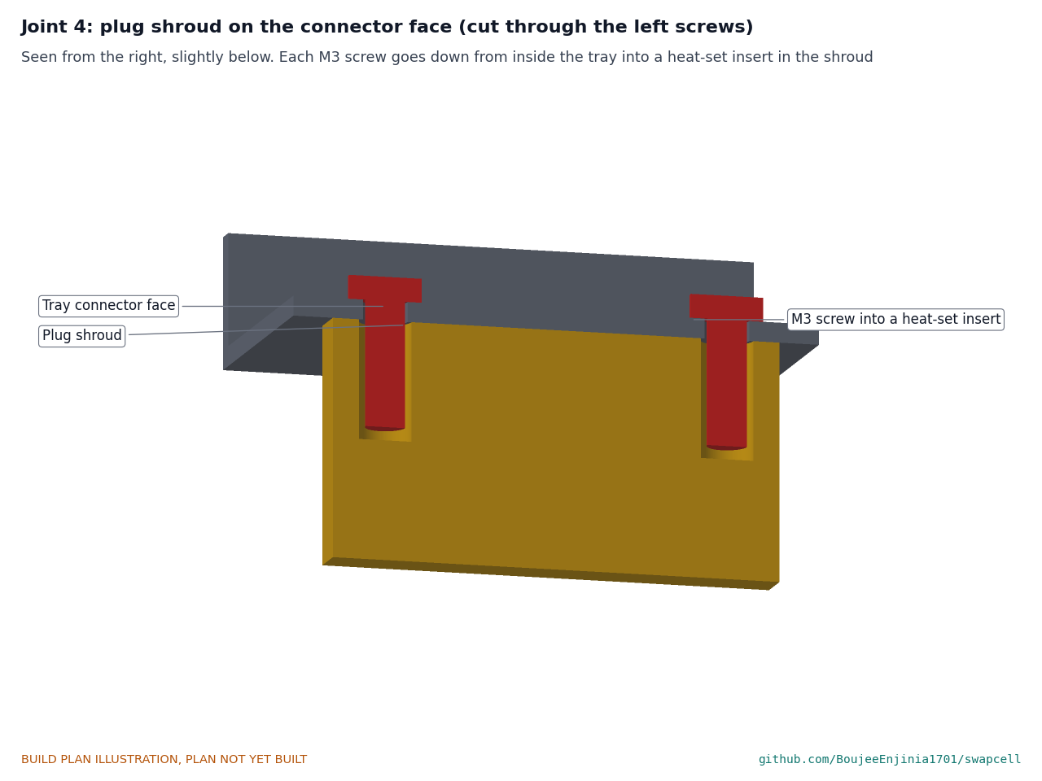
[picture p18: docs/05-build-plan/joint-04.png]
Figure 9. Joint 4: plug shroud on the connector face


*Figure 9. The shroud's top face sits flat on the connector face; screws come from inside the tray; wires go up through the lead opening.*

**How it fits the parts next to it.** The top face lies flat on the connector face, centred across and 8 mm toward the back from the depth centre line, held by four M3 screws from inside the tray (Figure 9), with a bead of sealant round the lead opening. In the dock it drops into the shelf pocket with 2 mm all round and meets the receptacle face to face (Figure 23).

**Check before moving on.** The key notch is at the back right seen from the lid; every contact is held firm; the wires are labelled.

### 3.6 Cell holder frames and the cell block

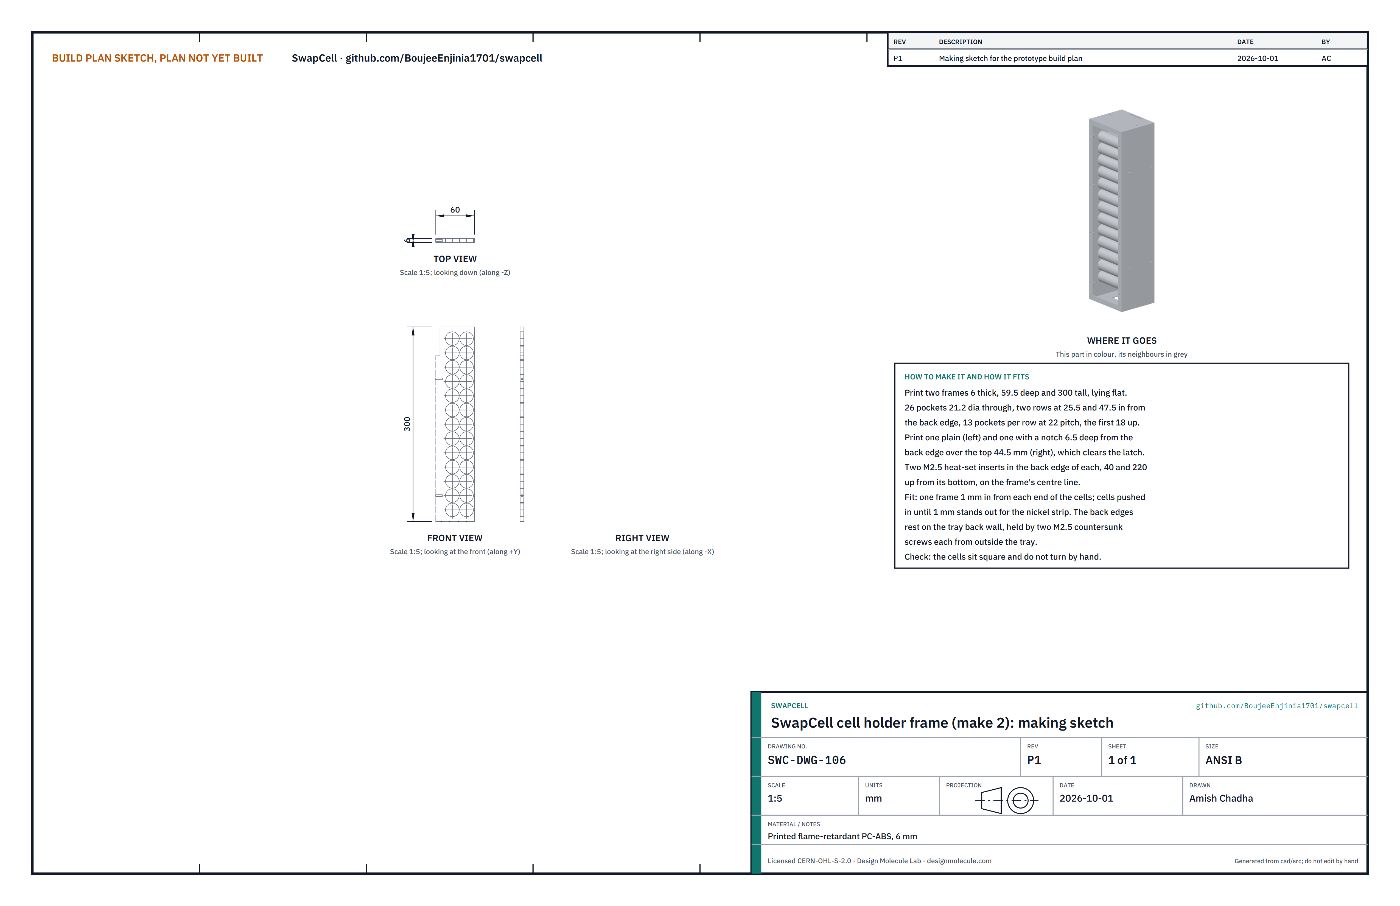
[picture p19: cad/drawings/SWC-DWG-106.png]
Figure 10. Making sketch of the cell holder frame


*Figure 10. Cell holder frame making sketch (SWC-DWG-106).*

**What it is and what it is made from.** Two printed frames that hold the 26 cells in two rows of 13 and locate the block on the back wall. Flame-retardant PC-ABS, 6 mm thick, printed flat.

**How to make it.**

1. Print two frames 6 thick, 59.5 deep and 300 tall. Each has 26 pockets 21.2 mm across, in two rows 25.5 and 47.5 mm in from the back edge, 13 per row at 22 mm pitch, the first 18 up from the bottom. Print one plain (the left frame) and one with a notch 6.5 deep from the back edge over its top 44.5 mm (the right frame), which clears the latch housing.
2. Fit two M2.5 heat-set inserts in the back edge of each frame, 40 and 220 up from its bottom.
3. Build the block (step 6): push the cells into both frames, all the same way round as the wiring needs, until 1 mm of each cell stands out of each frame.
4. Spot weld nickel strip across each pair to make 13 parallel groups, with a fuse wire from the strip to each cell, then join the groups in series, one group at a time. Never solder to a cell. Wrap the block in fish paper, leaving the sense lead tabs out.

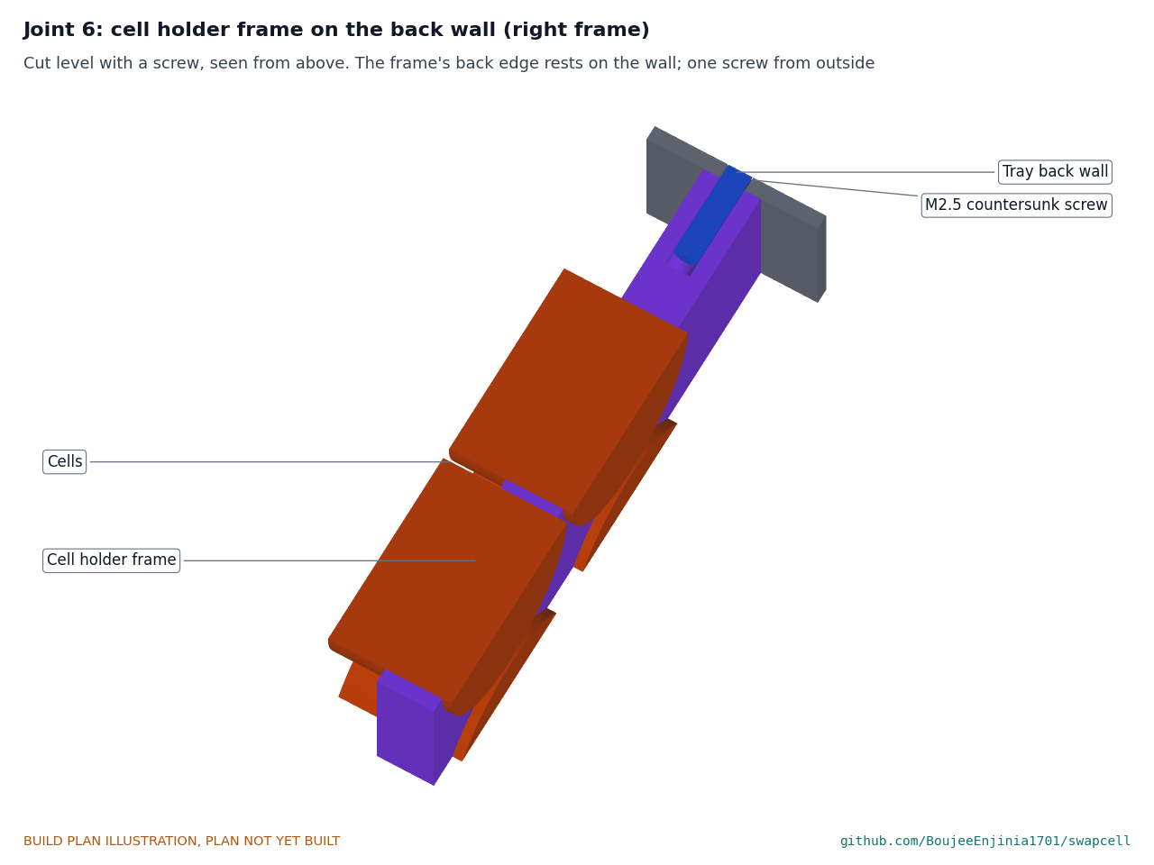
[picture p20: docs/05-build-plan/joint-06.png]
Figure 11. Joint 6: cell holder frame on the back wall


*Figure 11. Cut level with a screw: the right frame's back edge rests on the tray's back wall; one countersunk M2.5 screw from outside goes into an insert.*

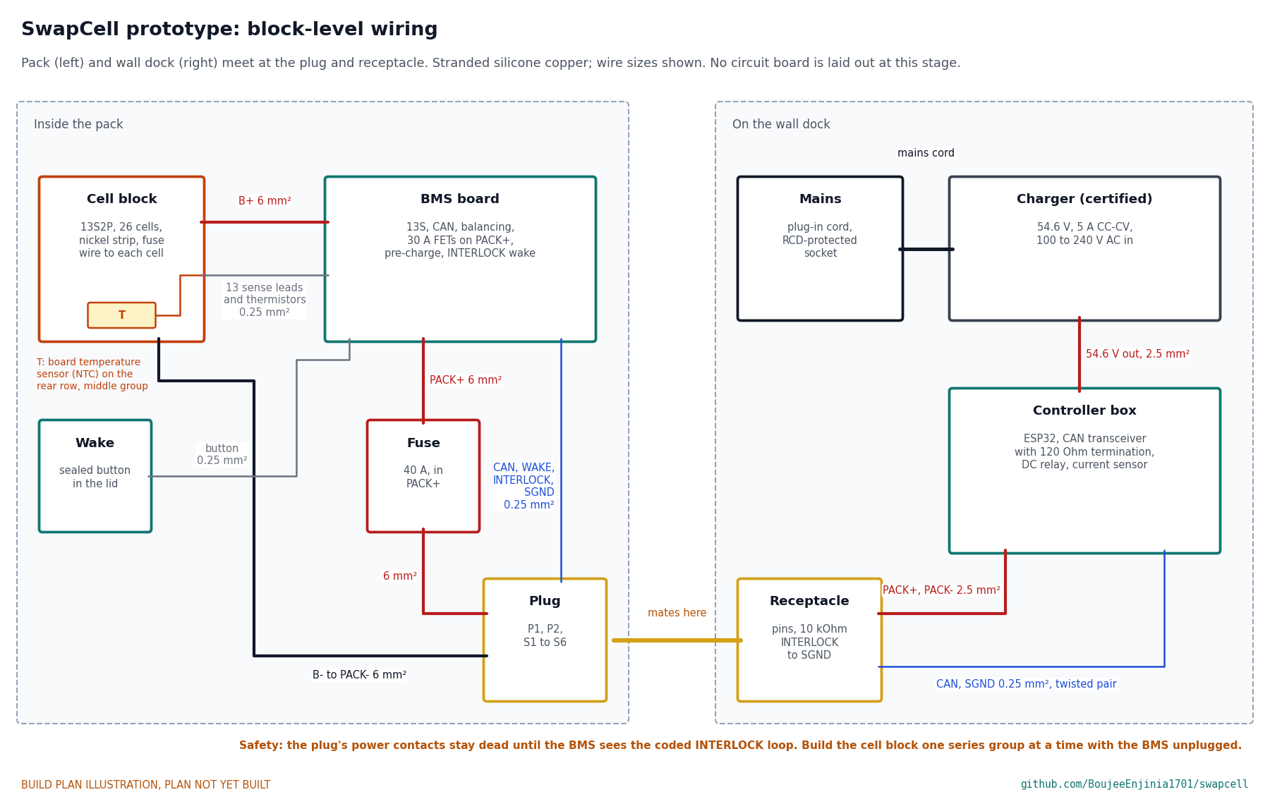
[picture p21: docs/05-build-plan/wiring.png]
Figure 12. Wiring at block level


*Figure 12. Block-level wiring with wire sizes. The board's temperature sensor (T) sits on the rear row of cells, on the middle group. No circuit board is laid out at this stage; the battery management board is bought.*

#### 3.6.1 Wiring

Wire the pack and dock as Figure 12, with stranded silicone copper:

1. Cell block positive to the battery management board's cell input: 6 mm² (10 AWG).
2. The board's switched output, through the 40 A main fuse, to the plug's PACK+ contact: 6 mm².
3. Cell block negative to the plug's PACK- contact and the board's ground: 6 mm².
4. Thirteen sense leads, one from each group, and the cell temperature sensors to the board's balance connector, with the board's temperature sensor taped along the middle cell of the rear row (the row nearer the back face), as Figure 12 shows: 0.25 mm², connected only at safety stop S3.
5. CAN high and low, WAKE, INTERLOCK and signal ground from the board to the plug: 0.25 mm², CAN as a twisted pair.
6. The wake button to the board's wake input: 0.25 mm².
7. In the dock: the receptacle's PACK+ and PACK- to the controller box's relay and current sensor and on to the charger output: 2.5 mm² (14 AWG); the receptacle's CAN and signal ground to the controller's CAN transceiver: 0.25 mm², twisted, with a 120 Ω termination in the controller. Solder the 10 kΩ coding resistor between the receptacle's INTERLOCK and signal ground pins.

**Check before moving on.** Each group reads within 0.05 V of the others; every fuse wire is intact; no bare metal can touch the tray.

### 3.7 Carry handle

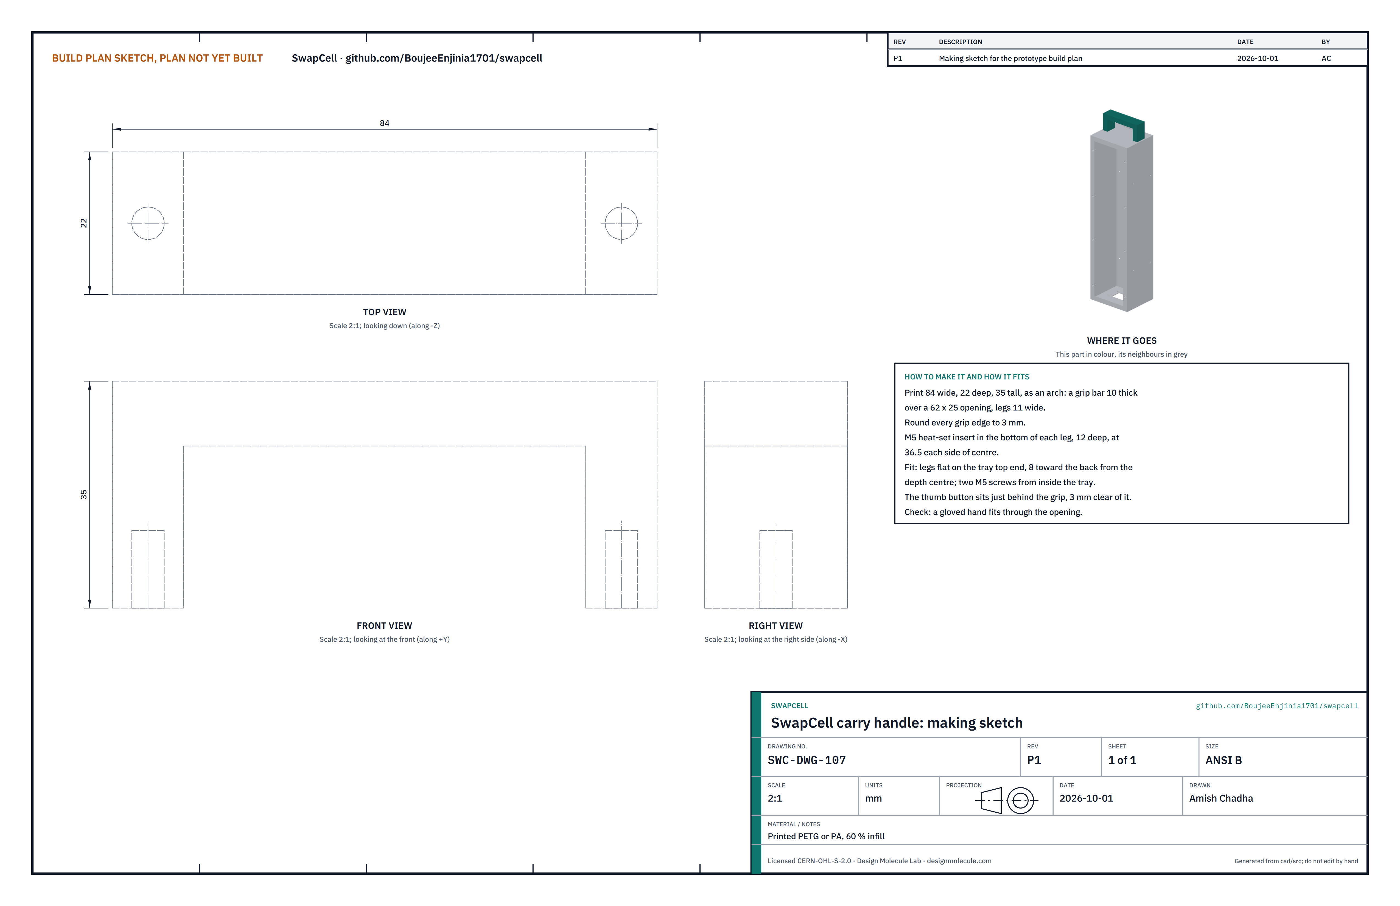
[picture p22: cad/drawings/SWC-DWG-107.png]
Figure 13. Making sketch of the carry handle


*Figure 13. Carry handle making sketch (SWC-DWG-107).*

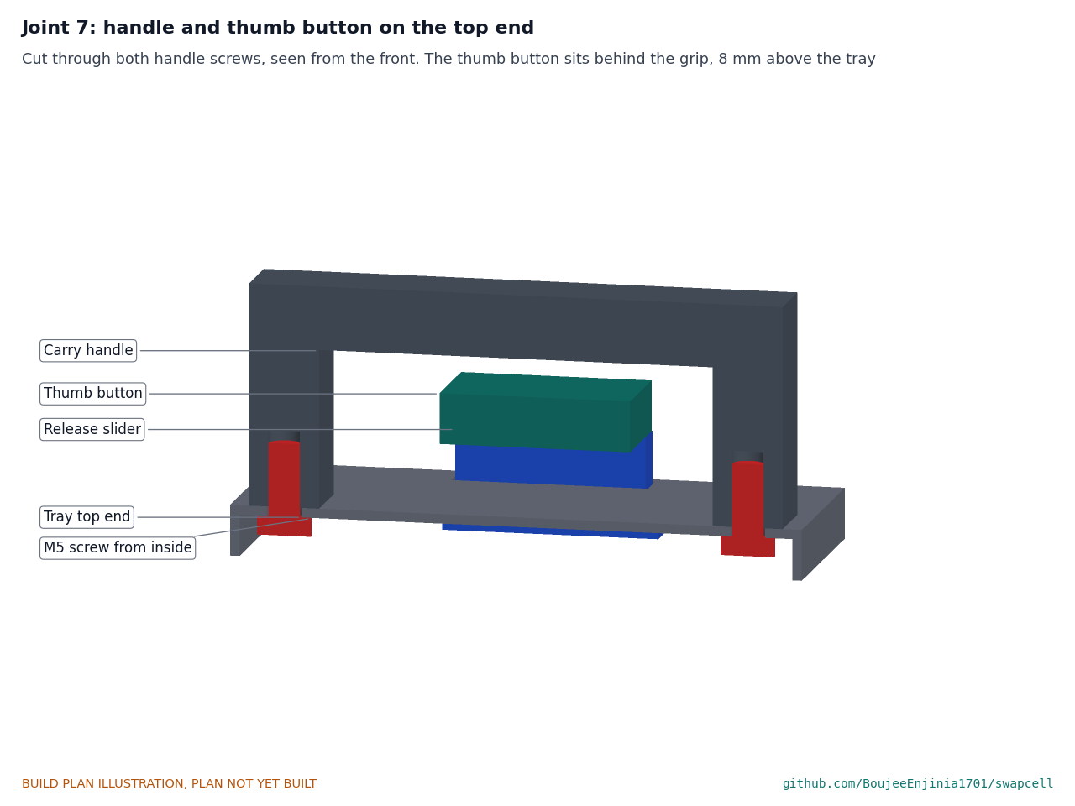
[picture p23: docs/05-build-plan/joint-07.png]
Figure 14. Joint 7: handle and thumb button on the top end


*Figure 14. Cut through both handle screws: two M5 screws from inside the tray hold the handle; the thumb button sits on the slider behind the grip.*

**What it is and what it is made from.** The loop on the top end that a gloved hand lifts the pack by. Printed PETG or nylon, 60 % infill.

**How to make it.**

1. Print 84 wide, 22 deep and 35 tall as an arch: a grip bar 10 thick over a 62 x 25 opening, on legs 11 wide. Round the grip edges to 3 mm.
2. Fit an M5 heat-set insert, 12 deep, in the bottom of each leg, 36.5 each side of centre.

**How it fits the parts next to it.** The legs sit flat on the top end, centred across and 8 mm toward the back from the depth centre line, held by two M5 screws up from inside the tray (Figure 14). The thumb button sits 3 mm behind the grip.

**Check before moving on.** A gloved hand fits through the opening and the thumb reaches the button.

### 3.8 Pack lid

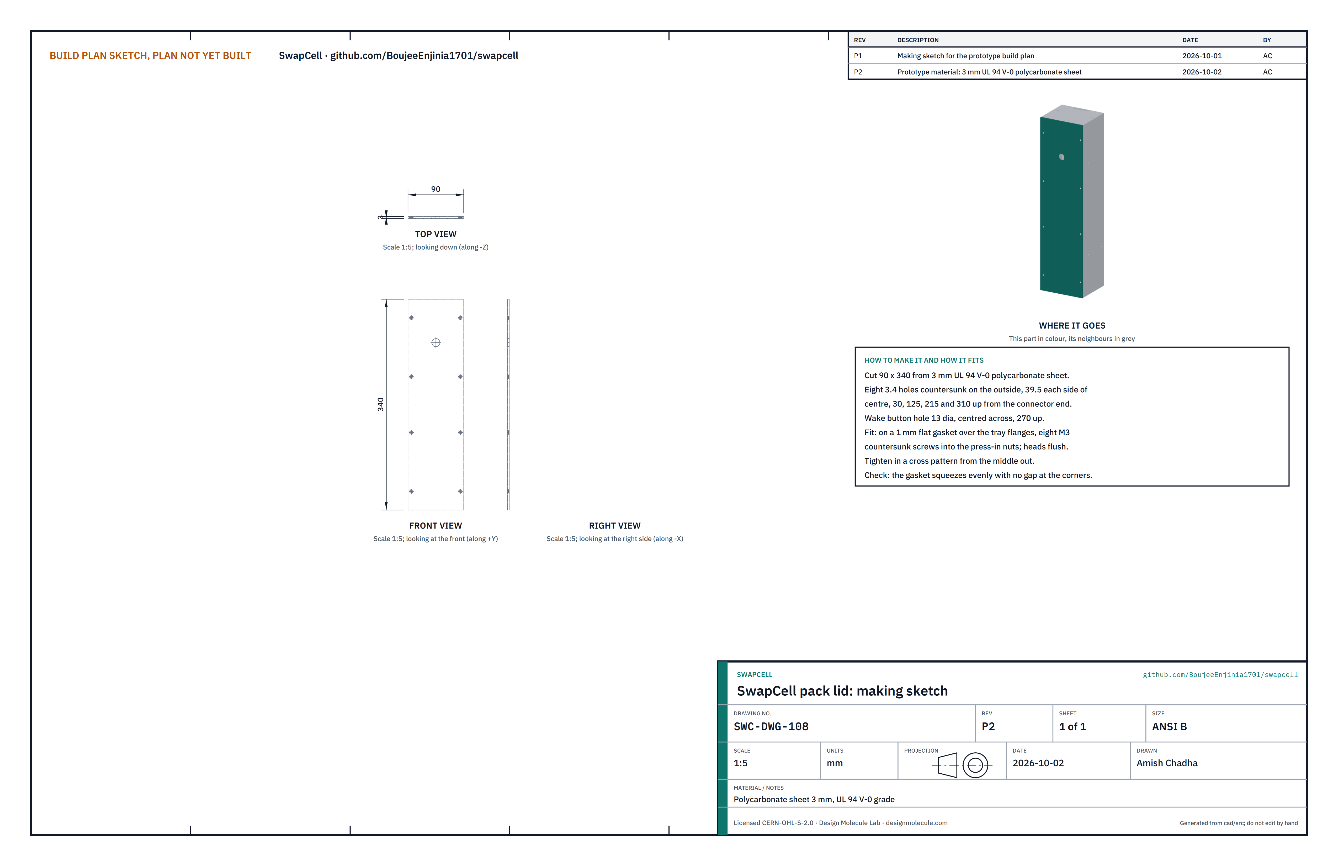
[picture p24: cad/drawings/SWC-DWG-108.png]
Figure 15. Making sketch of the pack lid


*Figure 15. Pack lid making sketch (SWC-DWG-108).*

**What it is and what it is made from.** The front face of the pack, removable for repair. For the prototype, cut from 3 mm UL 94 V-0 polycarbonate sheet. A lid printed in a V-0 grade polymer on a printer with a bed of at least 350 mm, to the same shape, is also allowed.

**How to make it.**

1. Cut a flat plate 90 x 340 from the 3 mm sheet with a fine-toothed saw or have the supplier cut it; smooth the edges.
2. Drill eight 3.4 mm holes, countersunk on the outside, 39.5 each side of centre, 30, 125, 215 and 310 up.
3. Drill the wake button hole 13 mm, centred across, 270 up.
4. Fit the sealed wake button with its nut inside.

**How it fits the parts next to it.** It sits on a 1 mm flat gasket over the tray's flanges, held by eight countersunk M3 screws into the press-in nuts, heads flush (Figure 3).

**Check before moving on.** On a trial fit, the gasket squeezes evenly with no gap at the corners, and the wake button body clears the cells.

### 3.9 Dock back plate

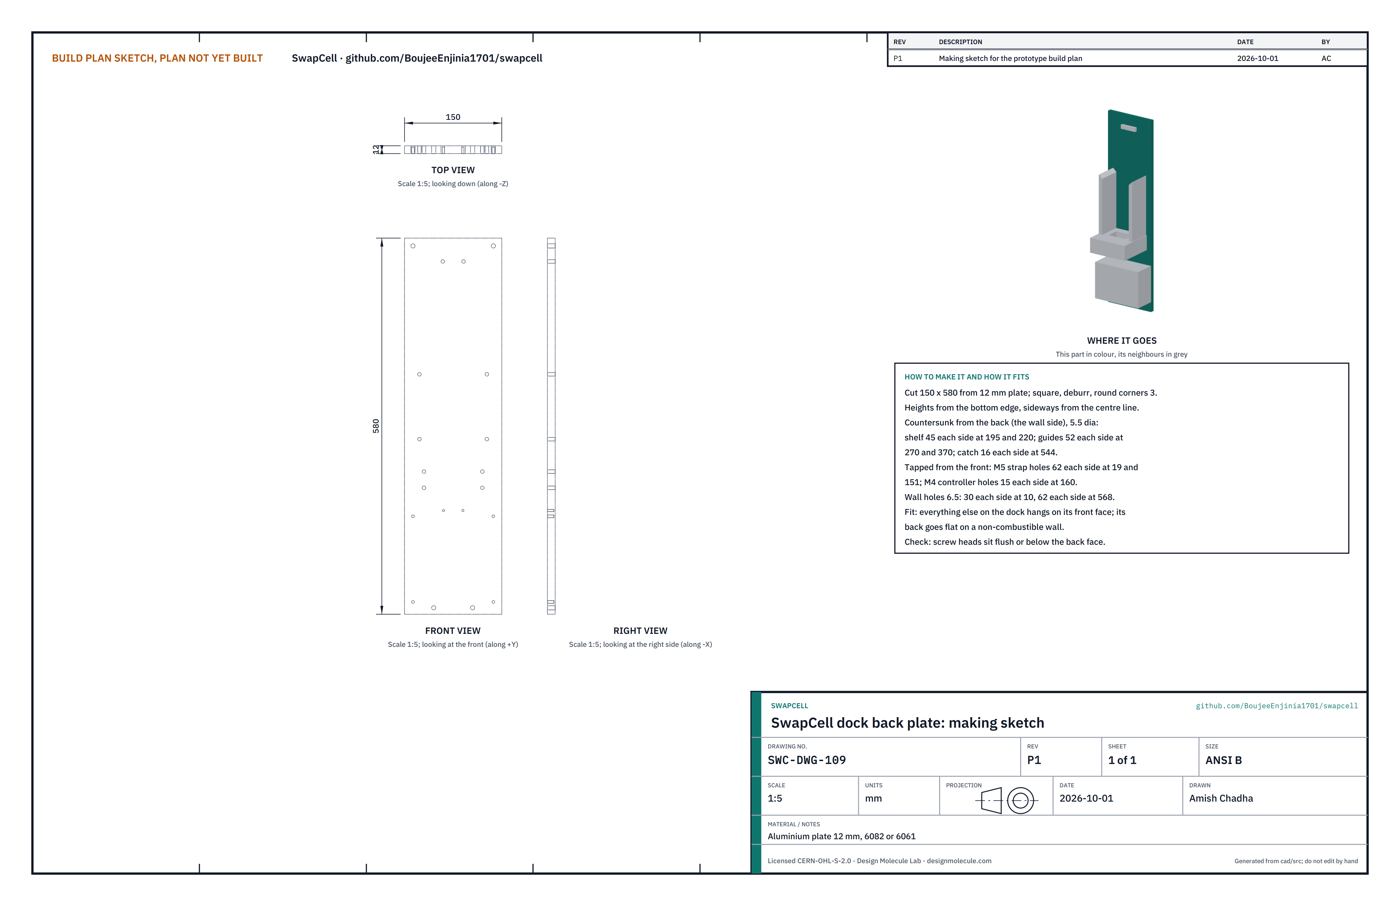
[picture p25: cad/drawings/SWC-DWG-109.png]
Figure 16. Making sketch of the dock back plate


*Figure 16. Dock back plate making sketch (SWC-DWG-109).*

**What it is and what it is made from.** The plate on the wall that every dock part hangs on. Aluminium plate 12 mm, 6082 or 6061.

**How to make it.**

1. Cut 150 x 580; square, deburr and round the corners to 3 mm. Scribe a centre line; heights below are from the bottom edge.
2. Drill 5.5 mm and countersink from the back (the wall side): four shelf holes 45 each side of centre at 195 and 220 up; four guide holes 52 each side at 270 and 370 up; two catch holes 16 each side at 544 up.
3. Drill and tap from the front: four M5 strap holes 62 each side of centre at 19 and 151 up; two M4 controller holes 15 each side at 160 up.
4. Drill four 6.5 mm wall holes: 30 each side of centre at 10 up, and 62 each side at 568 up.

**How it fits the parts next to it.** Every dock part sits flat on its front face; its back goes flat on the wall.

**Check before moving on.** The countersunk screw heads sit flush or just below the back face.

### 3.10 Cradle shelf

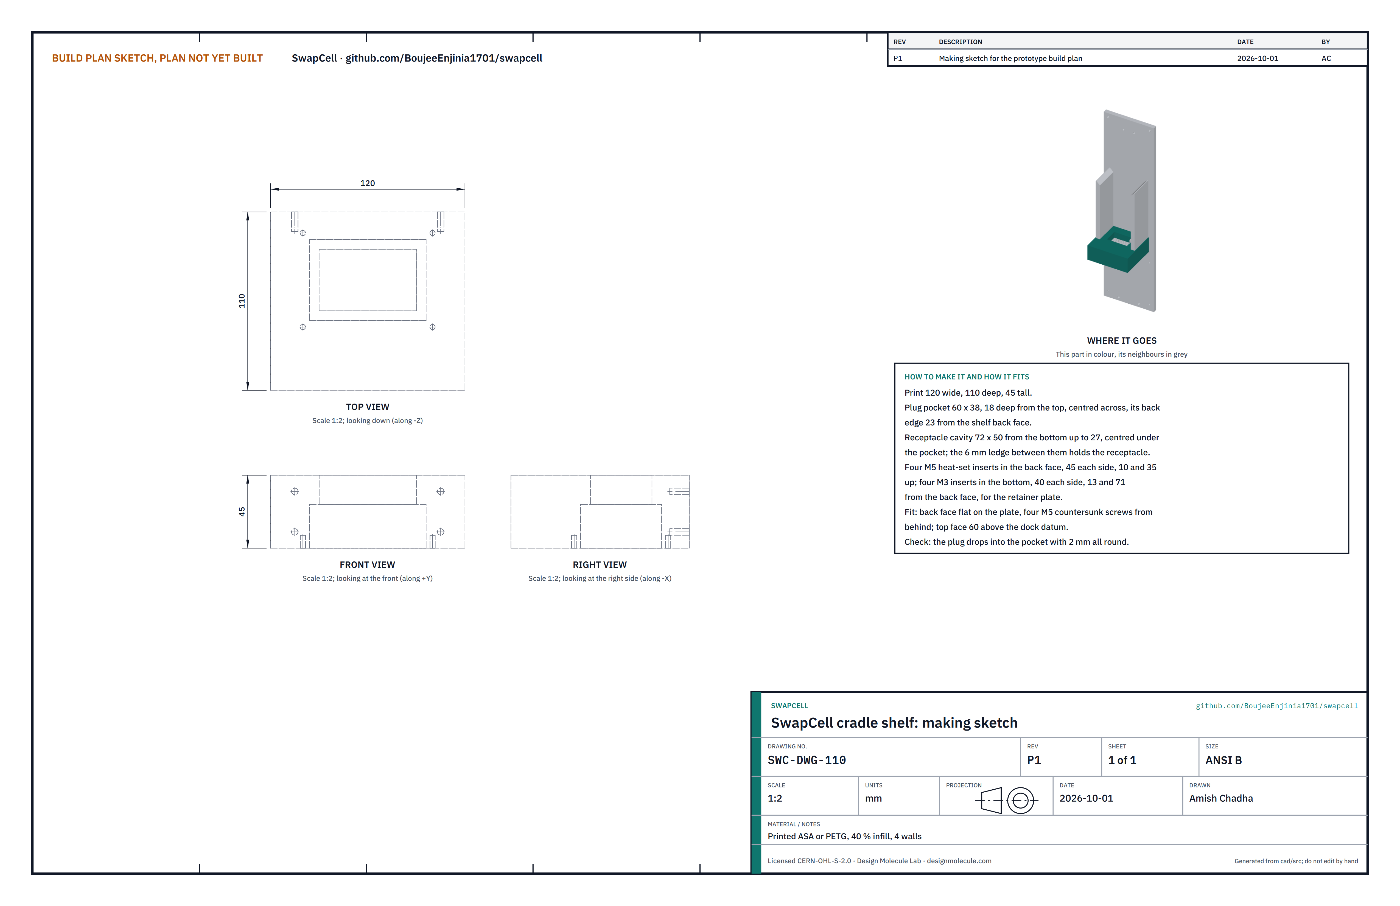
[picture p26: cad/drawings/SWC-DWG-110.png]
Figure 17. Making sketch of the cradle shelf


*Figure 17. Cradle shelf making sketch (SWC-DWG-110).*

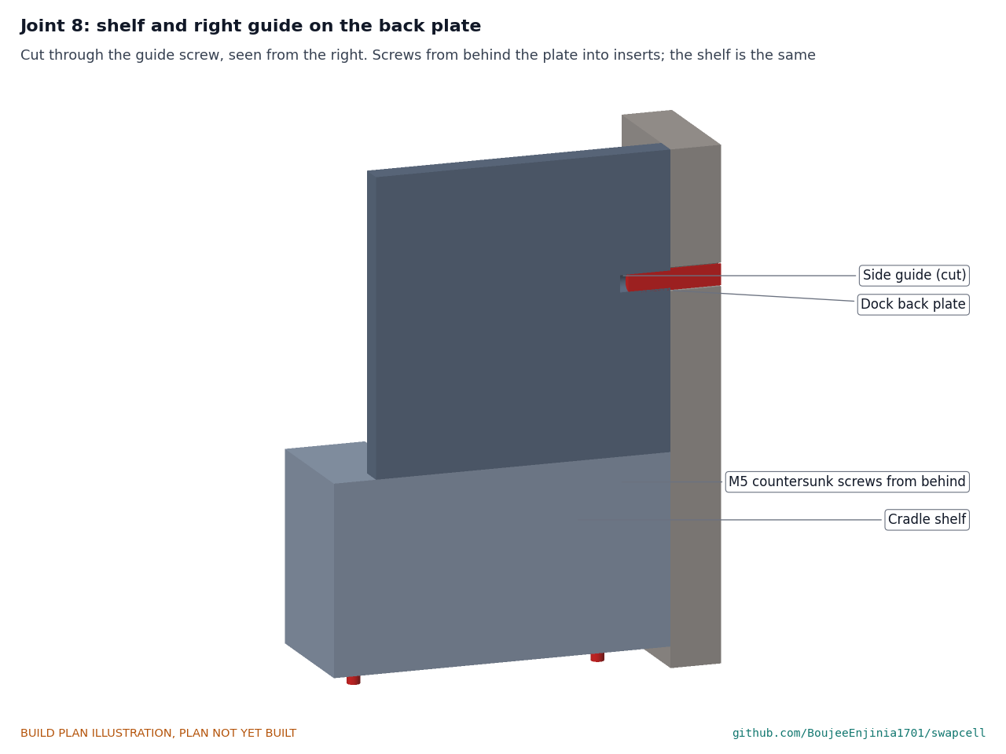
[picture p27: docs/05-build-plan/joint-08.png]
Figure 18. Joint 8: shelf and right guide on the back plate


*Figure 18. Countersunk M5 screws from behind the plate into inserts in the guide; the shelf is fixed the same way.*

**What it is and what it is made from.** The block the pack stands on, with the pocket for the plug and the cavity for the receptacle. Printed ASA or PETG, 40 % infill and four walls.

**How to make it.**

1. Print 120 wide, 110 deep and 45 tall.
2. The plug pocket is 60 x 38 and 18 deep from the top, centred across, its back edge 23 from the shelf's back face. The receptacle cavity is 72 x 50, from the bottom up to 27, centred under the pocket; the 6 mm ledge left between them holds the receptacle.
3. Fit four M5 heat-set inserts in the back face, 45 each side of centre, 10 and 35 up; and four M3 inserts in the bottom, 40 each side of centre, 13 and 71 in from the back face.

**How it fits the parts next to it.** The back face sits flat on the back plate, top 60 above the dock datum, held by four M5 countersunk screws from behind the plate (Figure 18). The pack stands on its top face; the plug drops into the pocket.

**Check before moving on.** The plug shroud drops into the pocket with 2 mm all round.

### 3.11 Side guides (make 2, a left and a right)

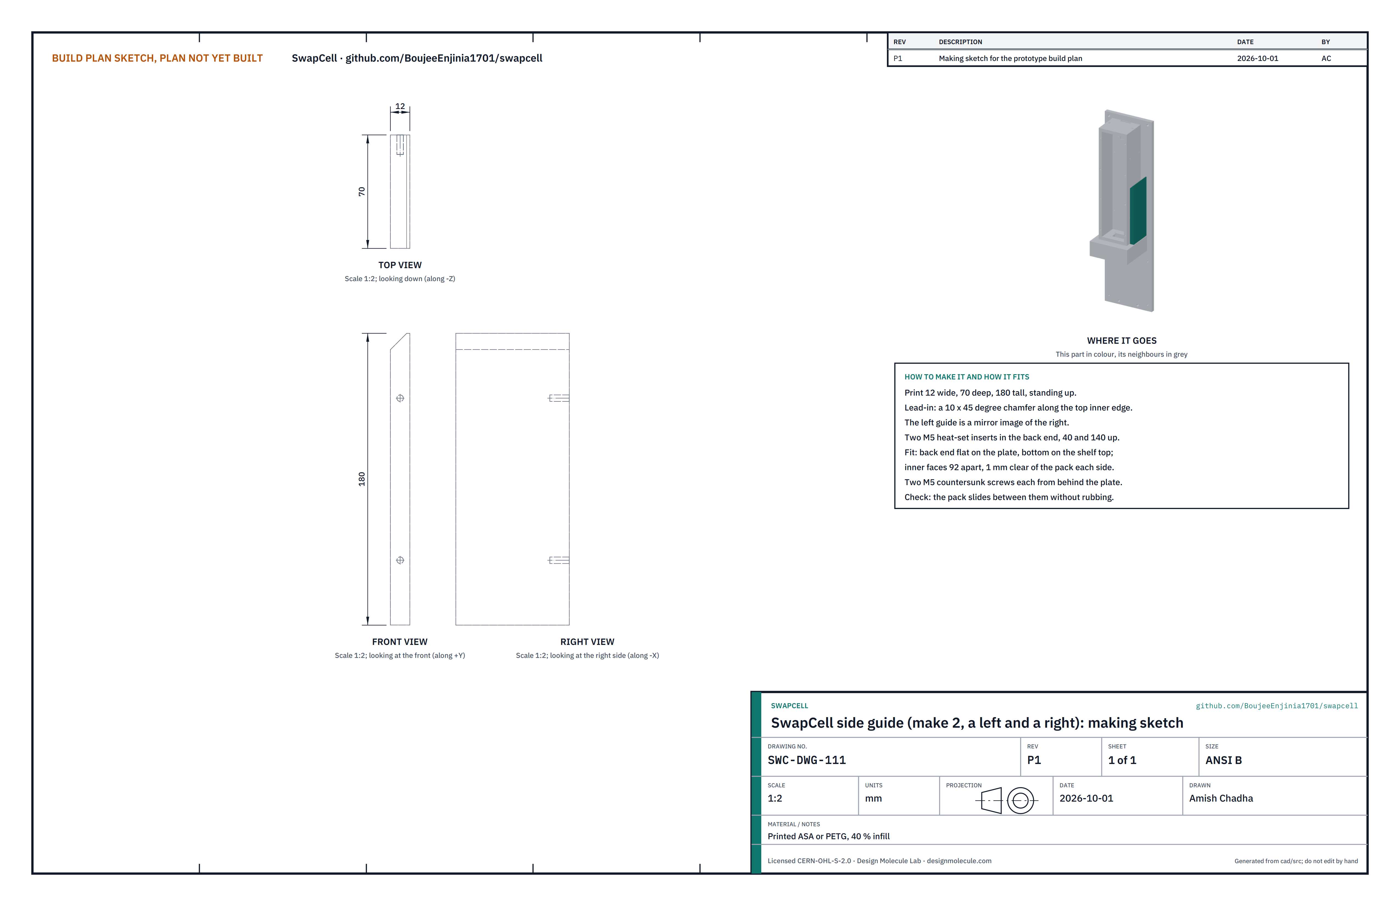
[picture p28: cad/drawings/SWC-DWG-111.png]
Figure 19. Making sketch of the side guide


*Figure 19. Side guide making sketch (SWC-DWG-111).*

**What it is and what it is made from.** Two printed rails either side of the pack that bring the plug within the receptacle's reach. Printed ASA or PETG, 40 % infill.

**How to make it.**

1. Print two, 12 wide, 70 deep and 180 tall, standing up; the left is a mirror image of the right.
2. Leave a 10 mm x 45 degree lead-in along the top inner edge.
3. Fit two M5 heat-set inserts in the back end of each, 40 and 140 up.

**How it fits the parts next to it.** Each back end sits flat on the back plate and its bottom on the shelf; inner faces 92 apart, 1 mm clear of the pack each side; two M5 countersunk screws from behind the plate (Figure 18).

**Check before moving on.** The pack slides between them without rubbing.

### 3.12 Latch catch

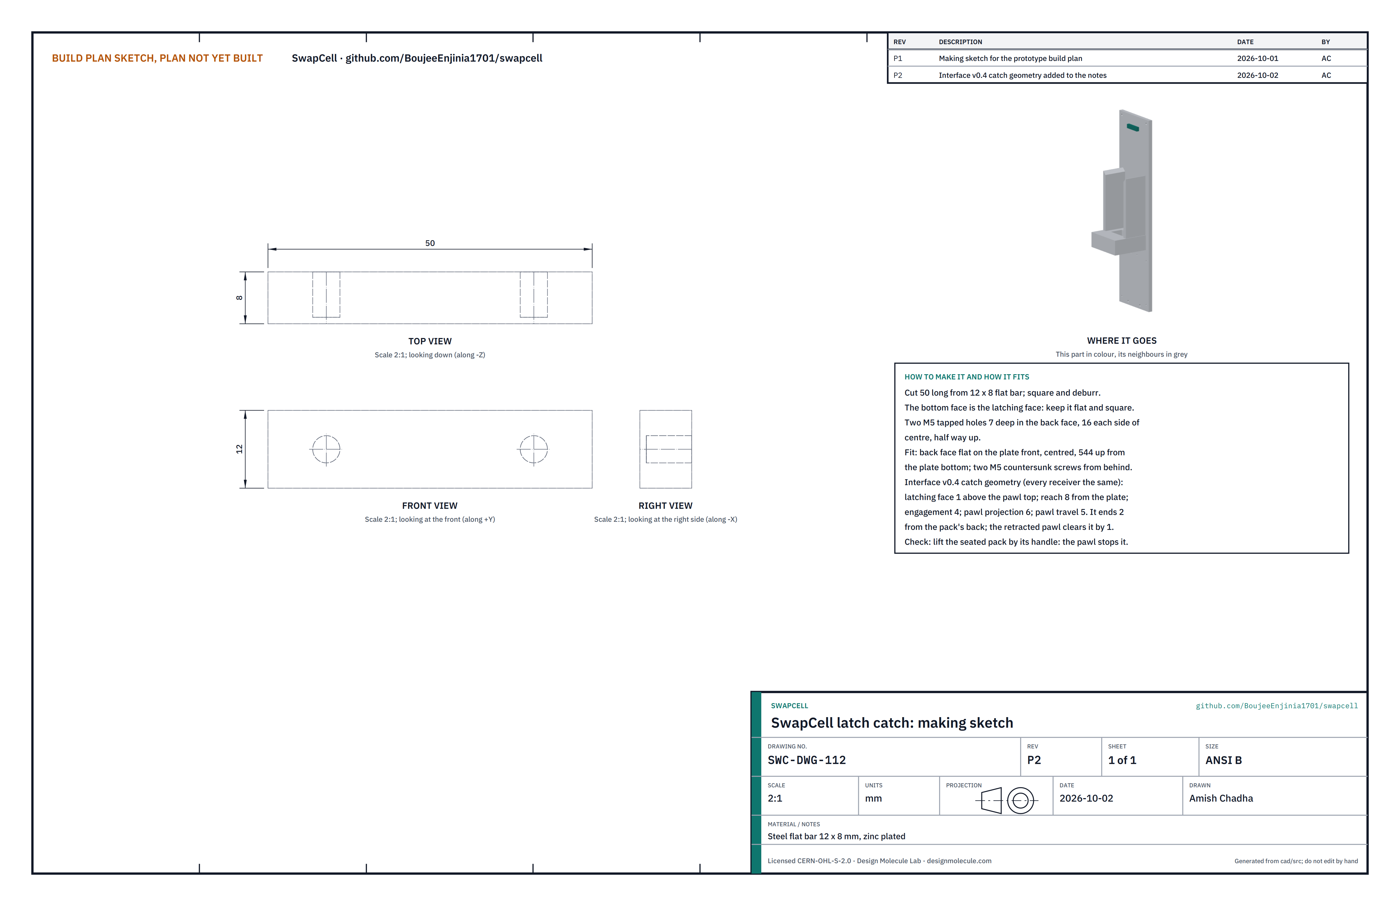
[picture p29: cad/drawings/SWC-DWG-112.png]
Figure 20. Making sketch of the latch catch


*Figure 20. Latch catch making sketch (SWC-DWG-112).*

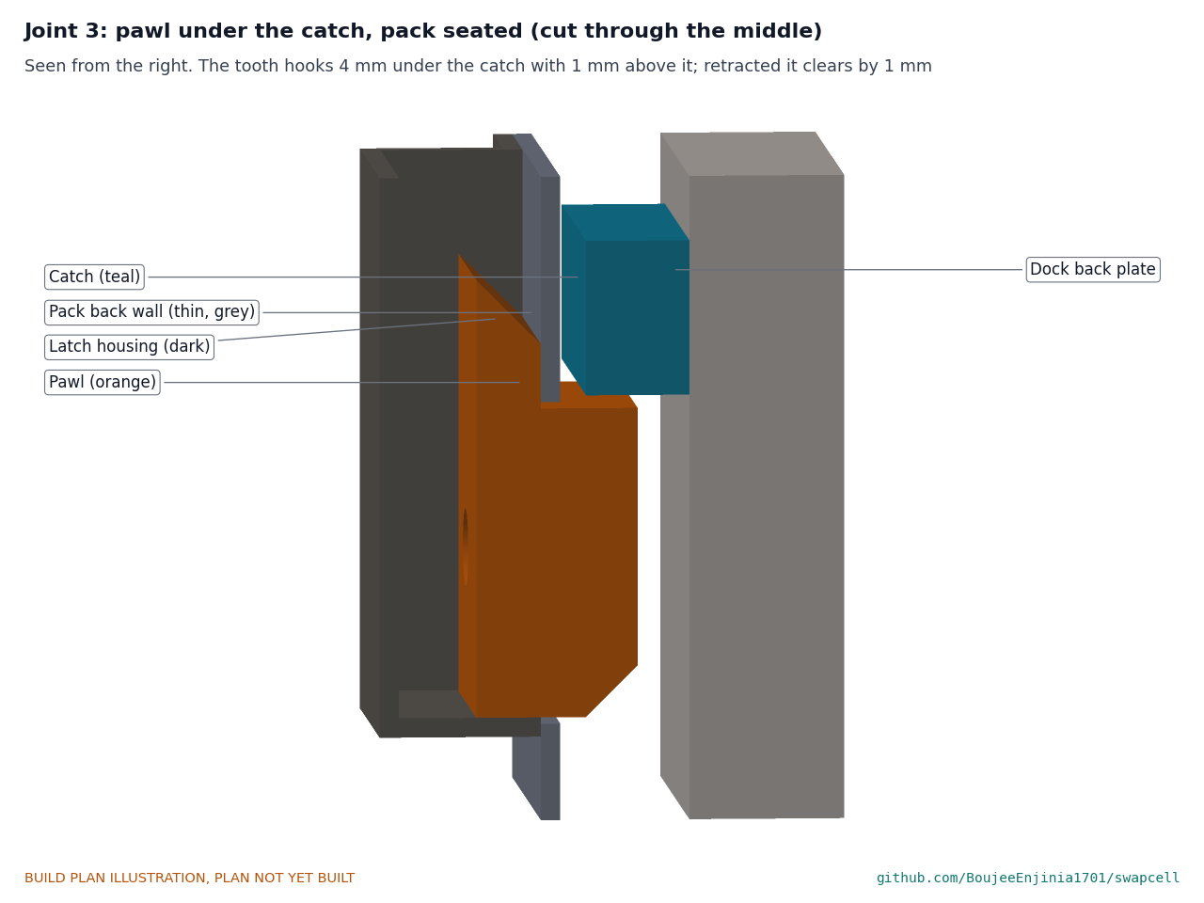
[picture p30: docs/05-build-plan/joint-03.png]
Figure 21. Joint 3: pawl under the catch


*Figure 21. With the pack seated, the tooth sits 1 mm under the catch and overlaps it by 4 mm; pressed in, it clears the catch by 1 mm.*

**What it is and what it is made from.** The steel bar on the plate that the pawl hooks under. Zinc-plated steel flat bar 12 x 8 mm.

**How to make it.**

1. Cut 50 long; square and deburr. The bottom face is the latching face: keep it flat and square.
2. Drill and tap two M5 holes 7 deep in the back face, 16 each side of centre, half way up.

**How it fits the parts next to it.** The back face sits flat on the plate front, centred, 544 up from the plate's bottom, on two M5 countersunk screws from behind. It stands 8 mm out from the plate and ends 2 mm short of the pack's back face. With the pack seated, the pawl sits 1 mm below it and overlaps it by 4 mm (Figure 21). These are the catch sizes every SwapCell receiver uses: latching face 1 mm above the pawl, reach 8 mm, engagement 4 mm, pawl standing 6 mm proud and moving 5 mm when released.

**Check before moving on.** With the pack in the dock, lifting it by the handle without pressing the button does not bring it out.

### 3.13 Receptacle shroud

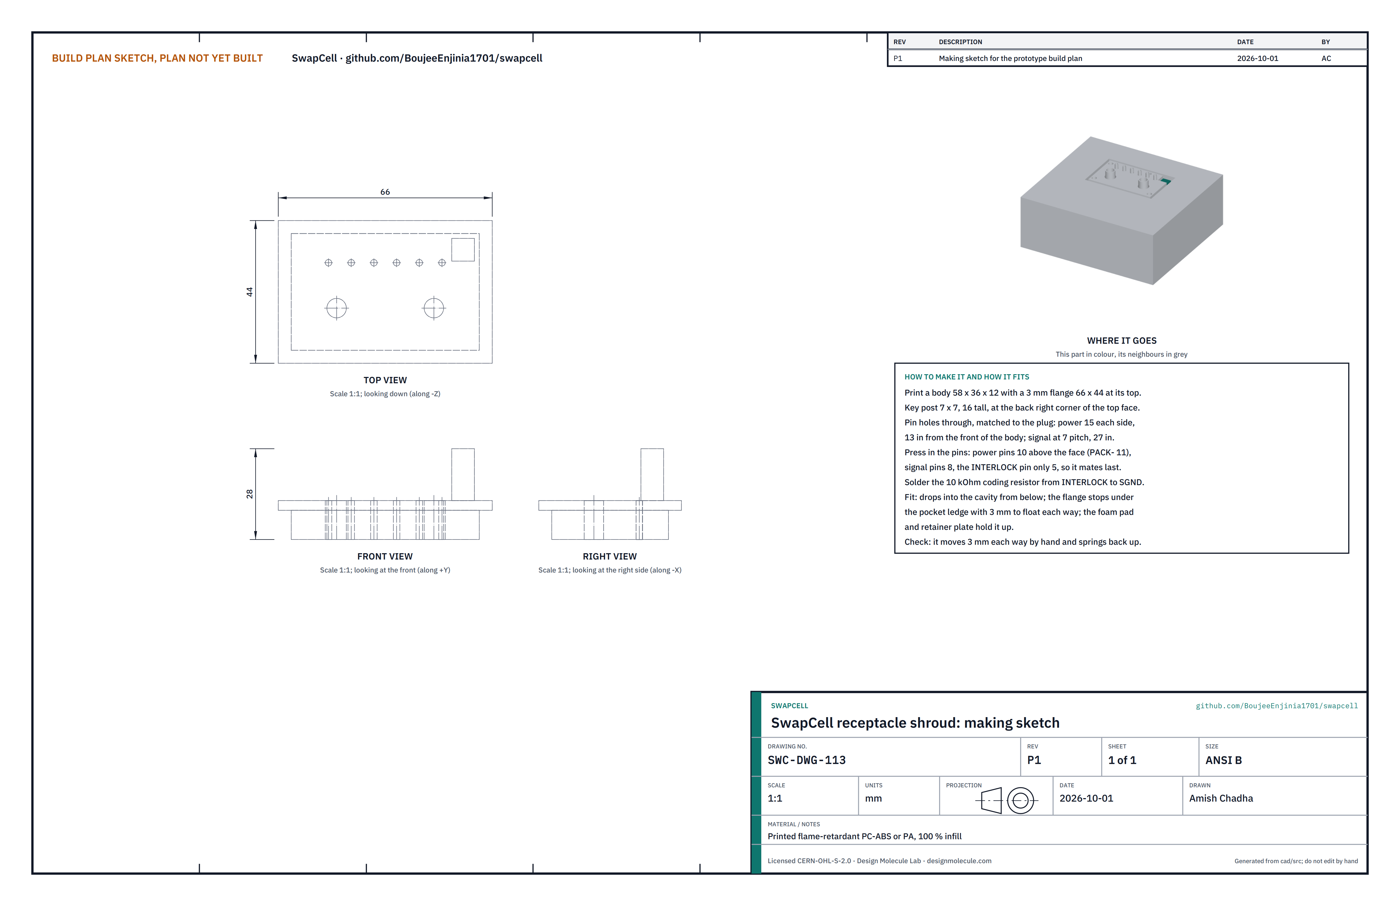
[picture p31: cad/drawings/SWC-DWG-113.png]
Figure 22. Making sketch of the receptacle shroud


*Figure 22. Receptacle shroud making sketch (SWC-DWG-113).*

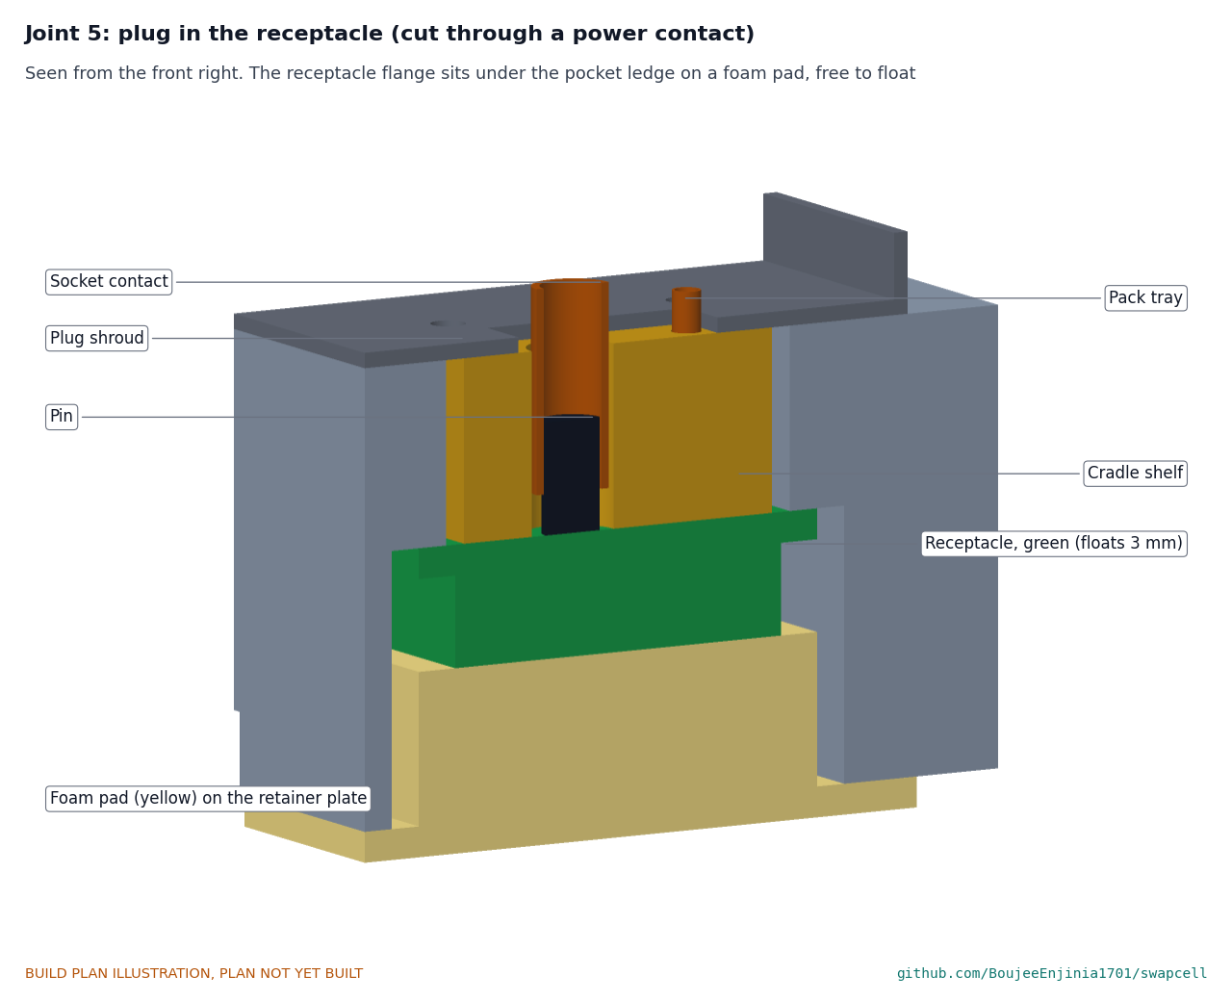
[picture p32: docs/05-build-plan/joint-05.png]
Figure 23. Joint 5: plug in the receptacle


*Figure 23. The plug meets the receptacle face to face; the receptacle's flange sits under the pocket's ledge on the foam pad, free to float.*

**What it is and what it is made from.** The dock half of the connector: a printed body carrying the pins, which floats in the shelf so the plug can find it. Flame-retardant PC-ABS or nylon at 100 % infill; the pins are bought to match the plug's contacts.

**How to make it.**

1. Print a body 58 x 36 x 12 with a 3 mm flange 66 x 44 round its top, and a key post 7 x 7, 16 tall, at the back right corner of the top face.
2. Pin holes through, matched to the plug: power pins 15 each side of centre, 13 in from the front of the body; signal pins at 7 mm pitch, 27 in.
3. Press in the pins: power pins 10 above the face (PACK- 11), signal pins 8, the INTERLOCK pin only 5, so it mates last.
4. Solder the 10 kΩ coding resistor from INTERLOCK to signal ground and the leads to the pin tails.

**How it fits the parts next to it.** It goes up into the shelf cavity from below; its flange stops under the ledge round the plug pocket with 3 mm free each way. The foam pad and retainer plate hold it up (Figure 23).

**Check before moving on.** It moves 3 mm each way by hand and springs back up level.

### 3.14 Receptacle retainer plate

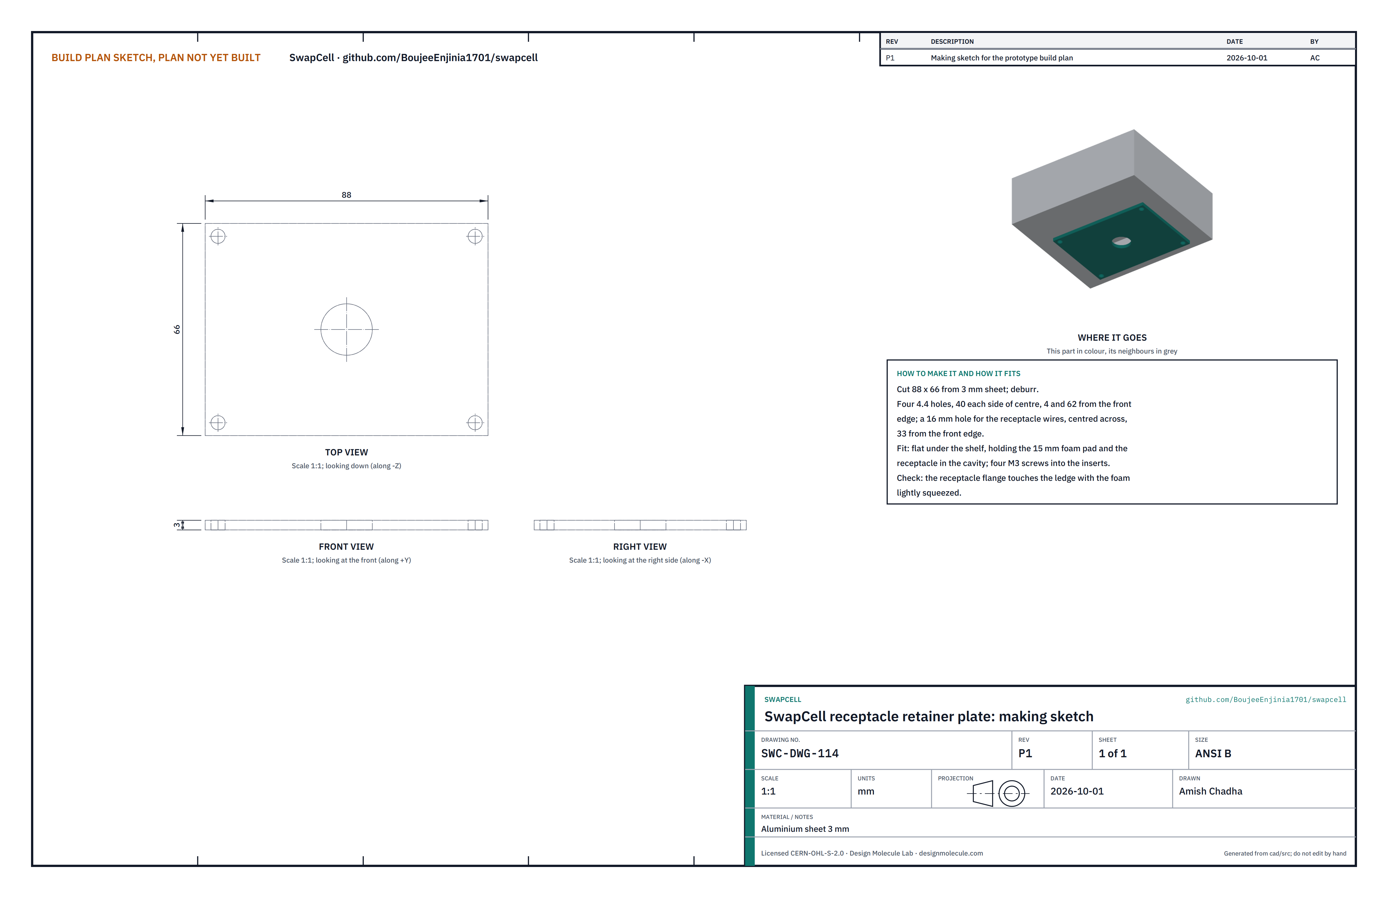
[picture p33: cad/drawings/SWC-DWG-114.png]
Figure 24. Making sketch of the receptacle retainer plate


*Figure 24. Retainer plate making sketch (SWC-DWG-114).*

**What it is and what it is made from.** The plate under the shelf that holds the foam pad and receptacle in. Aluminium sheet 3 mm, with a bought 15 mm closed-cell foam pad cut to 66 x 44.

**How to make it.**

1. Cut 88 x 66; deburr.
2. Drill four 4.4 mm holes 40 each side of centre, 4 and 62 from the front edge, and a 16 mm hole for the receptacle wires, centred across, 33 from the front edge, with a grommet.

**How it fits the parts next to it.** It lies flat under the shelf on four M3 screws into the inserts, squeezing the foam pad lightly against the receptacle.

**Check before moving on.** The receptacle's flange touches the ledge with the foam lightly squeezed.

### 3.15 Charger straps (make 2)

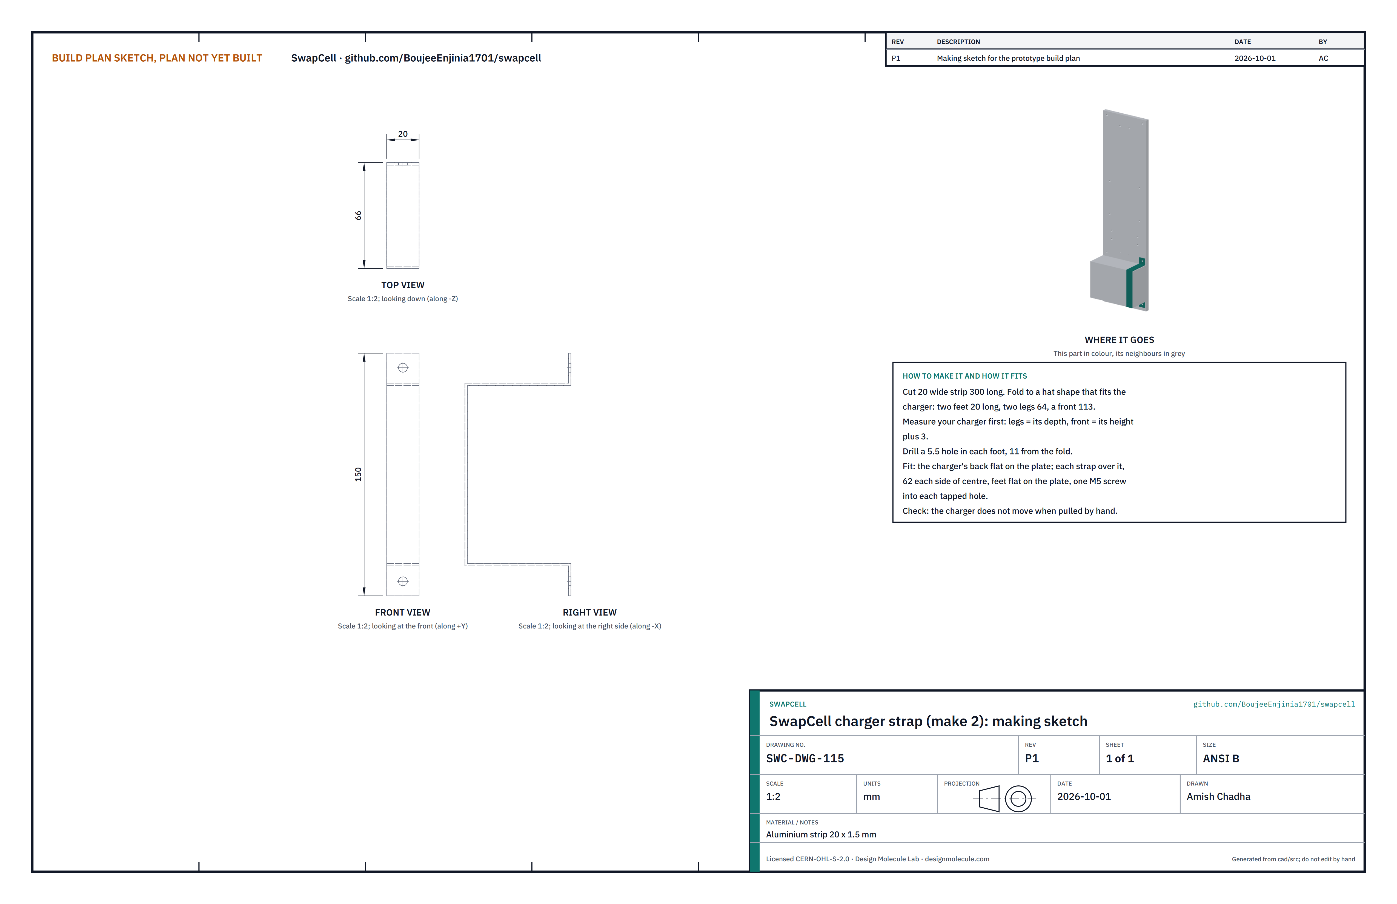
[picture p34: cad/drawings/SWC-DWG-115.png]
Figure 25. Making sketch of the charger strap


*Figure 25. Charger strap making sketch (SWC-DWG-115).*

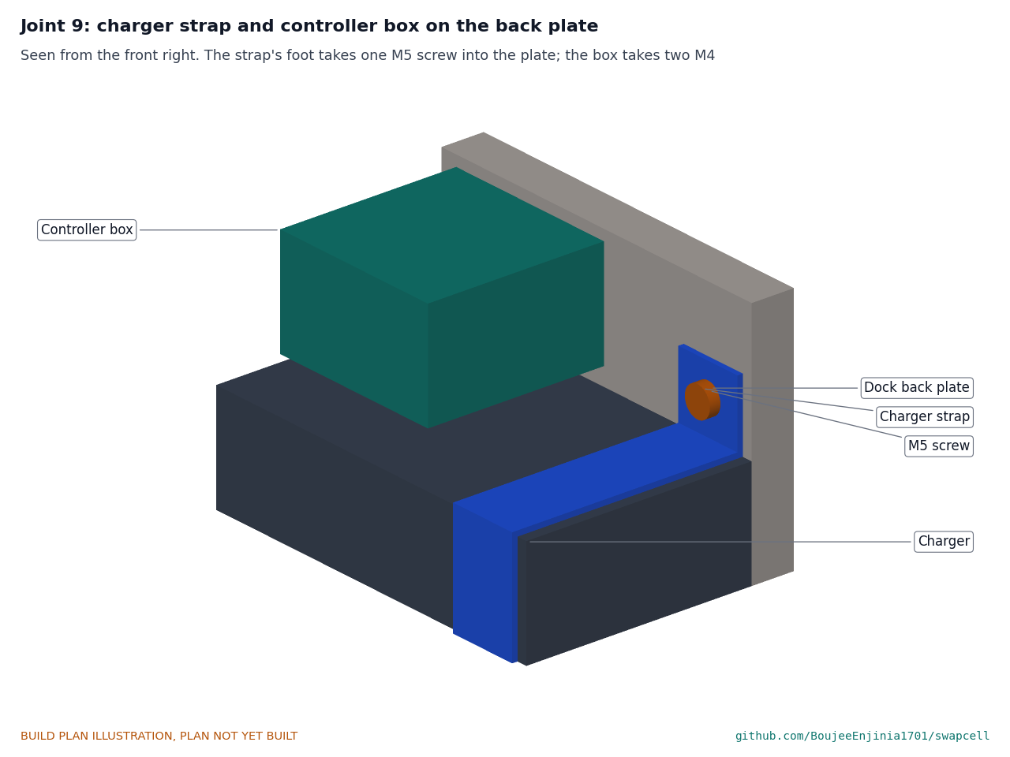
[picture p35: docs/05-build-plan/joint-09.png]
Figure 26. Joint 9: charger strap and controller box


*Figure 26. Each strap's foot takes one M5 screw into a tapped hole; the controller box sits on the plate between the charger and the shelf.*

**What it is and what it is made from.** Two folded strips that hold the bought charger on the plate without drilling it. Aluminium strip 20 x 1.5 mm.

**How to make it.**

1. Measure your charger. The straps here suit one 150 wide, 64 deep and 110 tall: legs equal its depth, the front its height plus 3.
2. Cut two 300 mm lengths and fold each to a hat shape: two feet 20 long, two legs 64, a front 113.
3. Drill a 5.5 mm hole in each foot, 11 from the fold.

**How it fits the parts next to it.** The charger's back sits flat on the plate below the shelf; each strap goes over it 62 each side of centre, feet flat on the plate, one M5 screw into each tapped hole (Figure 26).

**Check before moving on.** The charger does not move when pulled by hand.

### 3.16 Bought components

Buy to specification, not brand. Line numbers are those of the bill of materials.

- **Cells (line 2).** 26 new, matched 21700 lithium-ion cells, 5.0 Ah nominal, 3.6 V, rated 25 A or more continuous, from an authorized distributor with a datasheet.
- **Battery management board (line 3).** Open-source 13-cell board with CAN 2.0B, balancing, 30 A switches on the positive side, pre-charge, a flash log, sleep current 100 µA or less and a wake input on INTERLOCK, about 230 x 58 mm and 10 mm thick or less.
- **Contacts (lines 5 and 9).** Two 40 A power socket contacts and six signal socket contacts for the plug, with matching pins for the receptacle; the INTERLOCK pair shortest.
- **Charger (line 10).** Certified 54.6 V, 5 A constant-current, constant-voltage lithium-ion charger, 100 to 240 V AC input, settable to 53.3 V.
- **Controller (line 11).** ESP32 board with a CAN transceiver, DC relay, current sensor and microSD, in a 50 x 50 x 30 mm box.
- **Fuses and wiring (line 12).** 40 A main fuse and holder, pre-charge resistor, fuse wire, nickel strip, 6 mm² and 0.25 mm² silicone wire, fish paper, thermistors.
- **Seals and fixings (line 13).** 1 mm closed-cell flat gasket, eight M3 press-in nuts and eight M3 x 8 countersunk screws (lid); four M3 x 10 screws and heat-set inserts (plug); two M5 x 12 screws and inserts (handle); four M2.5 x 8 countersunk screws and inserts (cell frames); four 2 mm standoffs and M2.5 countersunk screws (battery management board); six 4 mm countersunk blind rivets (latch housing); 3.2 mm blind rivets (tray tabs); flame-retardant liner sheet.
- **Wake button (line 14).** Sealed momentary switch, IP67 class, 12 mm, panel mounted, no more than 15 mm deep behind the panel.
- **Springs (line 15).** Two compression springs about 5 mm across and 14 mm long.
- **Dock mounting parts (line 17).** 15 mm closed-cell foam, M5 countersunk screws and heat-set inserts, M3 retainer screws, two M4 controller screws, four 6 mm wall screws and anchors.

## 4. Putting it together

In each picture the parts already fitted are grey and the part being fitted is in colour, with an arrow showing the way it goes in.

### Step 1: press-in nuts into the tray flanges

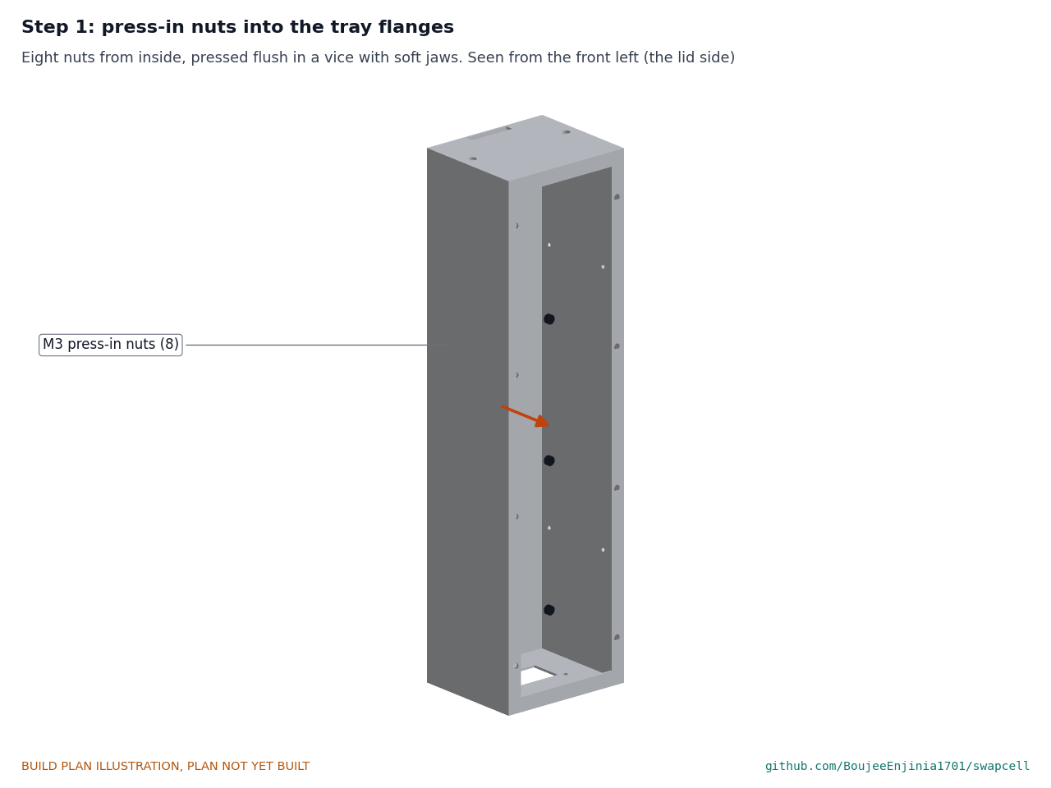
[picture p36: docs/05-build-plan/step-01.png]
Step 1


Eight M3 nuts from inside, pressed flush in a vice with soft jaws (if not already done in section 3.1).

### Step 2: pawl and release slider into the back wall

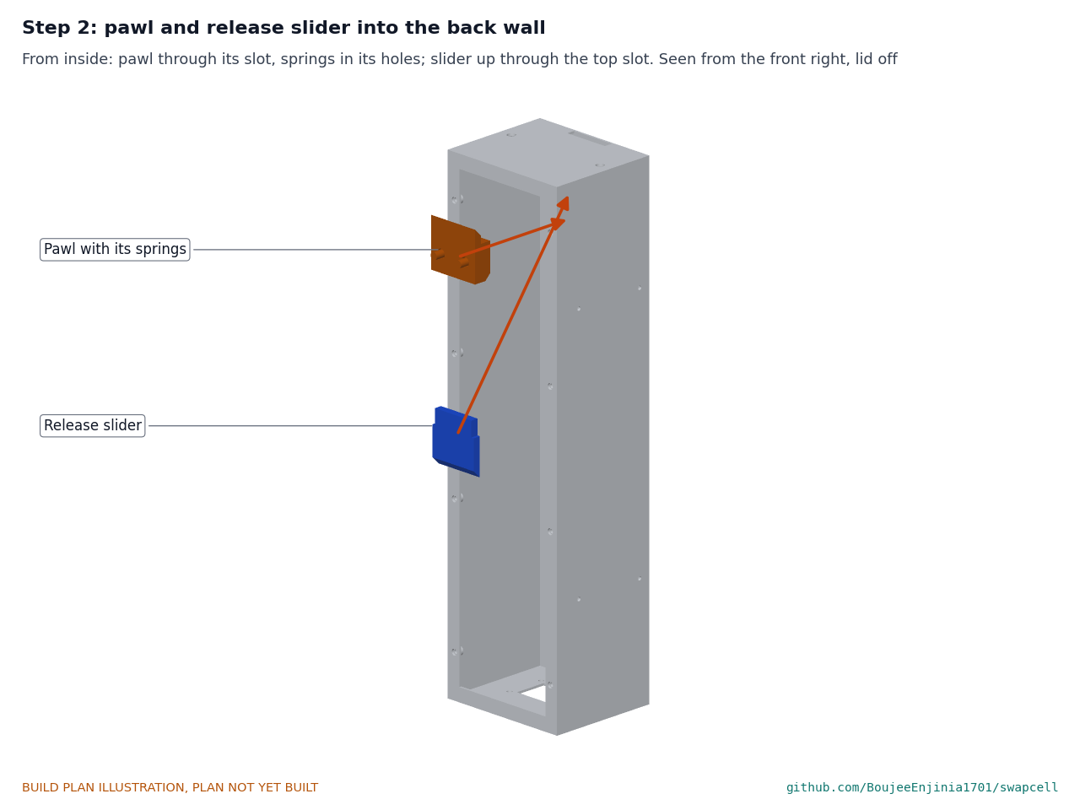
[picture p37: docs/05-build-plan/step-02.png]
Step 2


From inside the tray: put the springs in the pawl's holes and pass the pawl's tooth out through its slot, shoulder up against the wall. Pass the slider's narrow end up through the slot in the top end, ramp down on the pawl's ramp.

### Step 3: latch housing over them

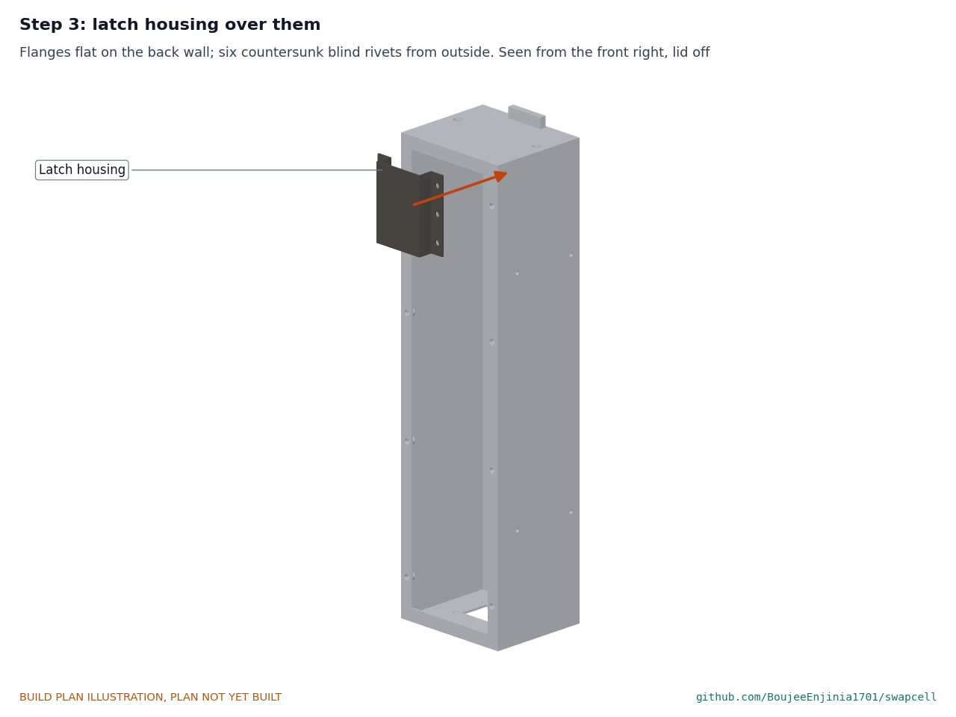
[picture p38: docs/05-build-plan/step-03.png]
Step 3


Hold the housing over the pawl and slider, flanges flat on the back wall, springs against its front. Six countersunk blind rivets from outside, heads flush.

### Step 4: thumb button onto the slider

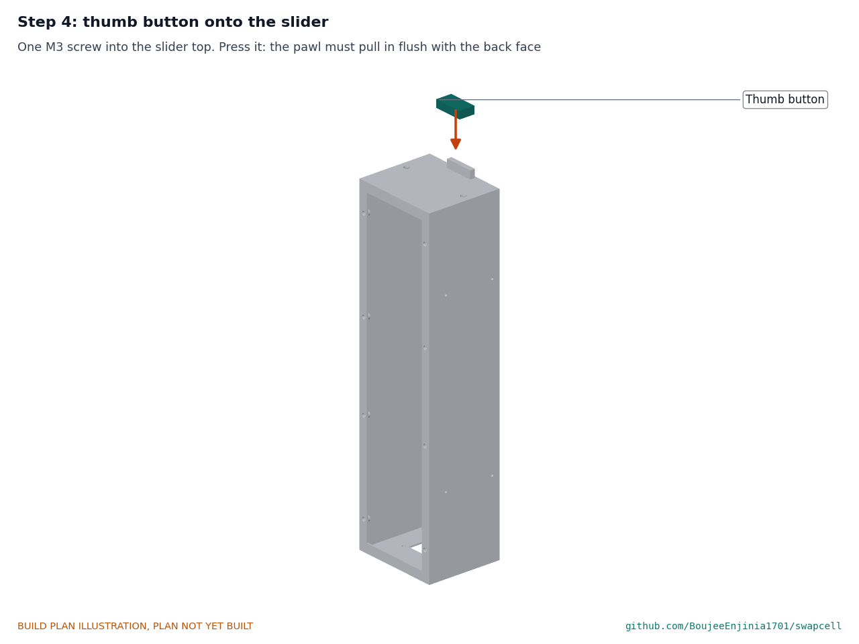
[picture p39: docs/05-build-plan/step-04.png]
Step 4


One M3 screw through the button into the slider's top. Press the button: the tooth must pull in flush with the back face and spring back out.

### Step 5: plug shroud onto the connector face

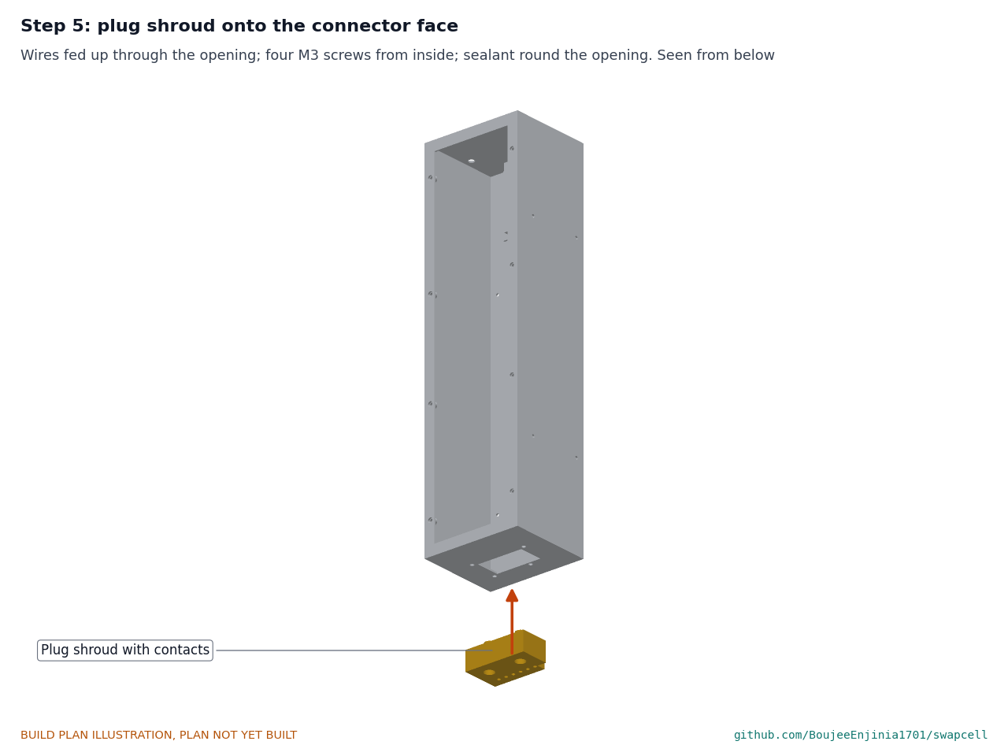
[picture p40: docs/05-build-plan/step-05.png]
Step 5


Feed the plug's wires up through the lead opening, seat the shroud with the key notch at the back right, and fit four M3 screws from inside. Run a bead of sealant round the opening.

### Step 6: build the cell block

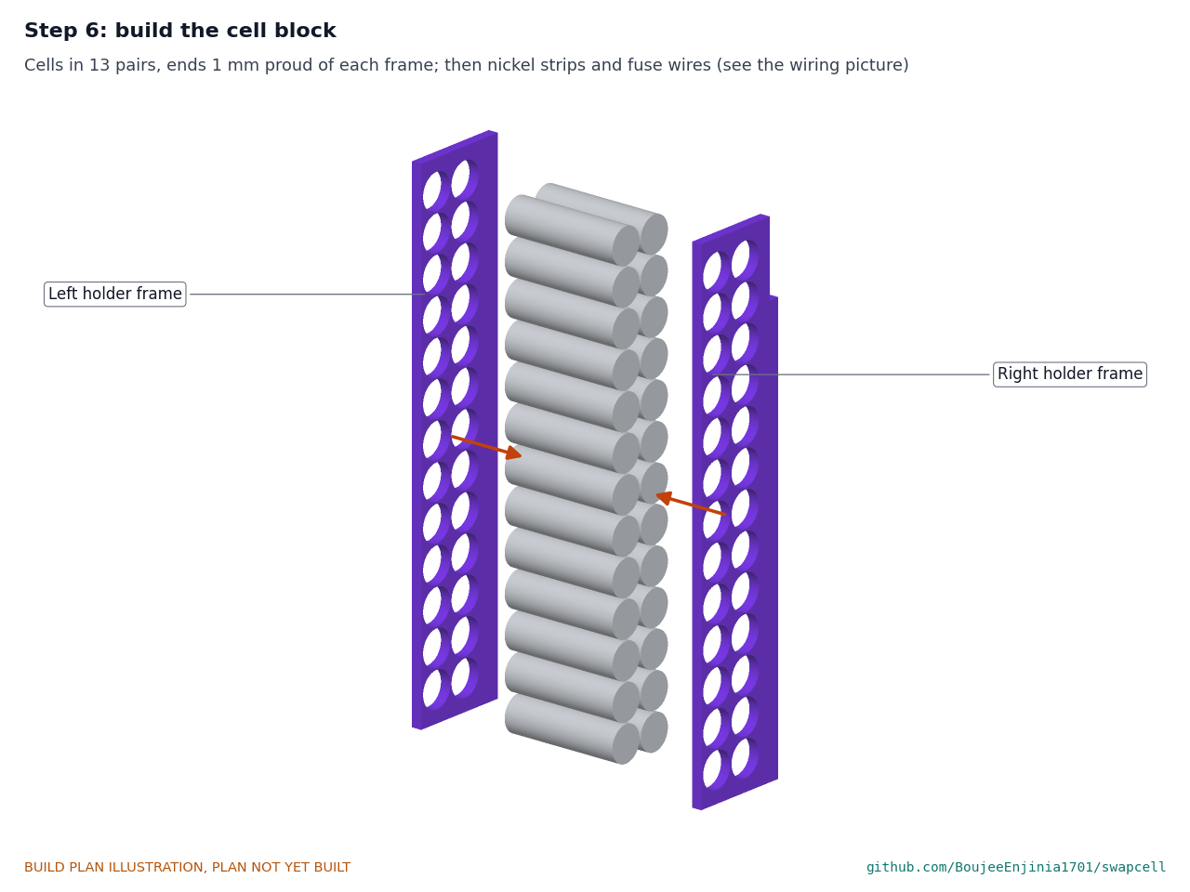
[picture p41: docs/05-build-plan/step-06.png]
Step 6


Push the 26 cells into both frames, then strip, fuse-wire and join the groups as section 3.6, one group at a time. **Hold point:** safety stops S1 and S2.

### Step 7: cell block into the tray

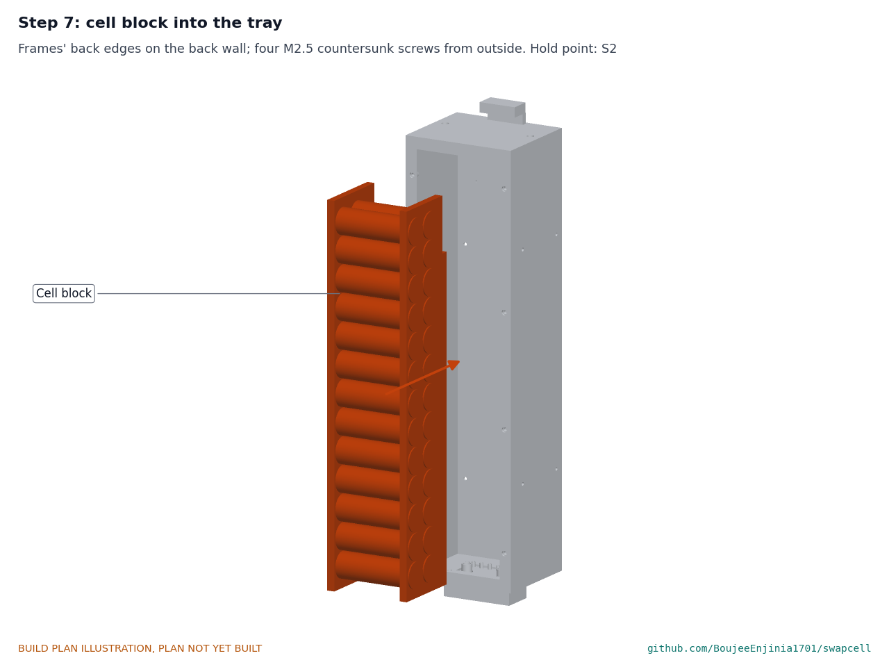
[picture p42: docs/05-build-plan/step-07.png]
Step 7


Lower the wrapped block into the tray with the frames' back edges on the back wall and fit four M2.5 countersunk screws from outside. Check no cell or strip touches the tray or the latch housing.

### Step 8: battery management board onto the right side wall

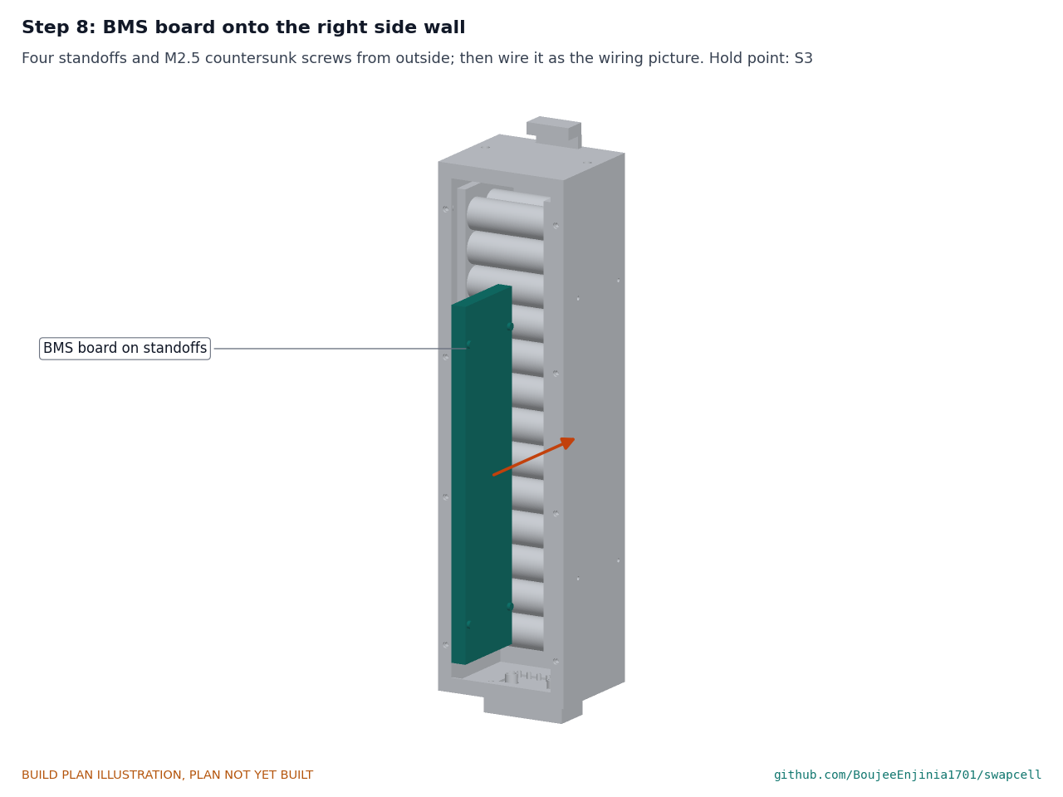
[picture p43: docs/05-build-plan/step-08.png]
Step 8


Fit the board on its four standoffs with M2.5 countersunk screws from outside, components toward the wall, and wire it as Figure 12 with the main fuse out. **Hold point:** safety stop S3.

### Step 9: carry handle onto the top end

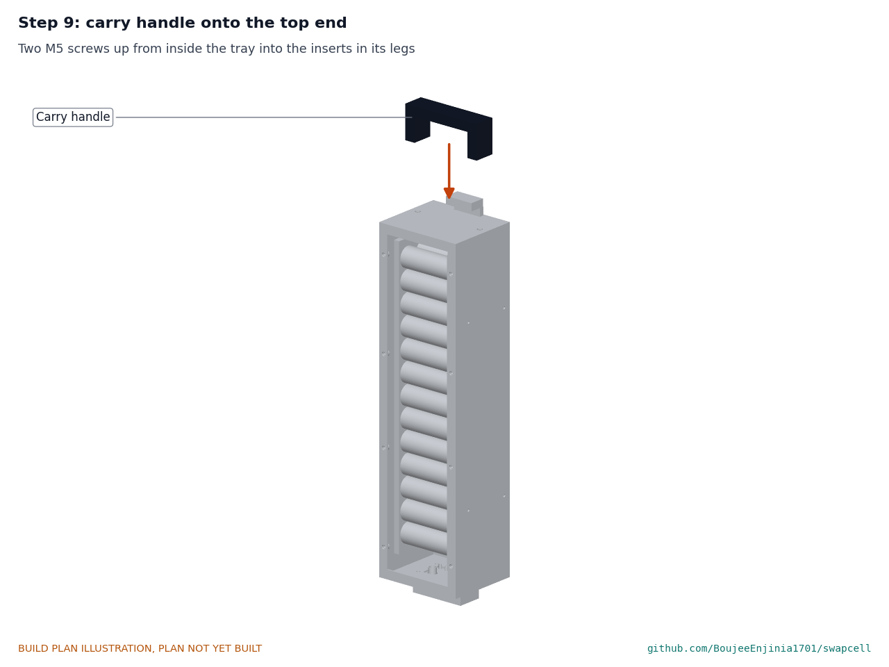
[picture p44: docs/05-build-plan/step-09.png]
Step 9


Two M5 screws up from inside the tray into the inserts in the legs.

### Step 10: gasket and lid

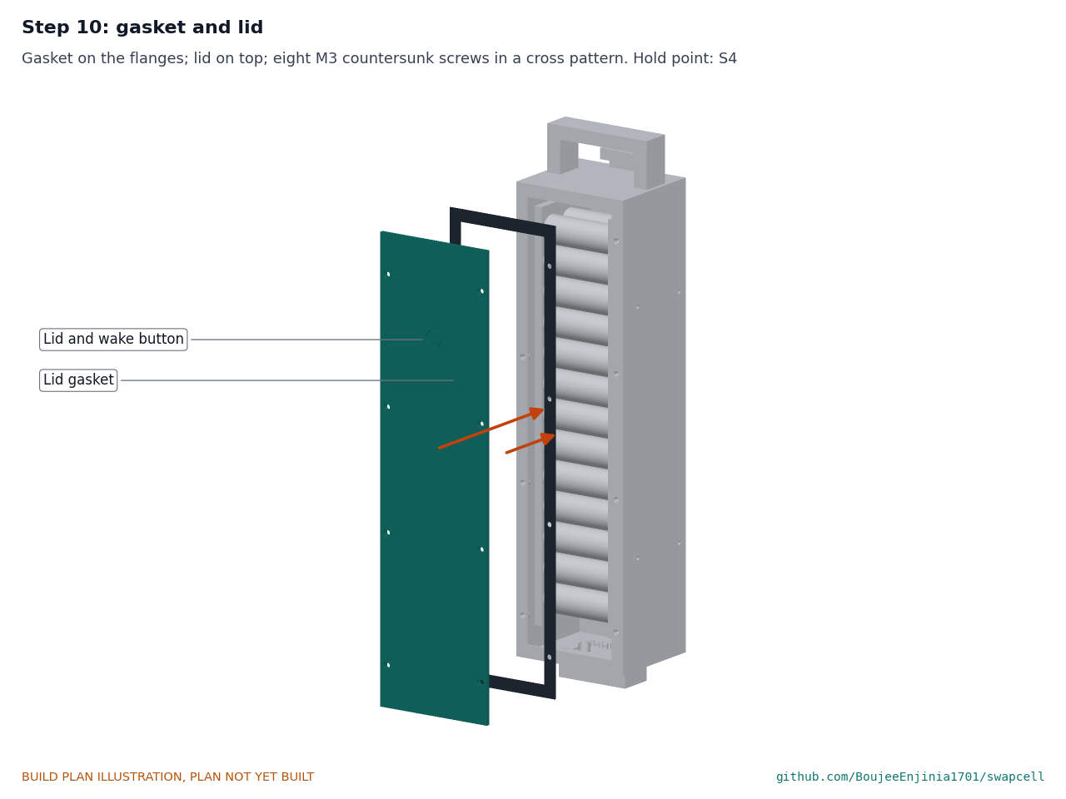
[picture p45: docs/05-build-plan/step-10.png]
Step 10


Stick the gasket on the flanges, fit the main fuse, add the lid and tighten its eight screws in a cross pattern from the middle out. **Hold point:** safety stop S4.

### Step 11: cradle shelf onto the back plate

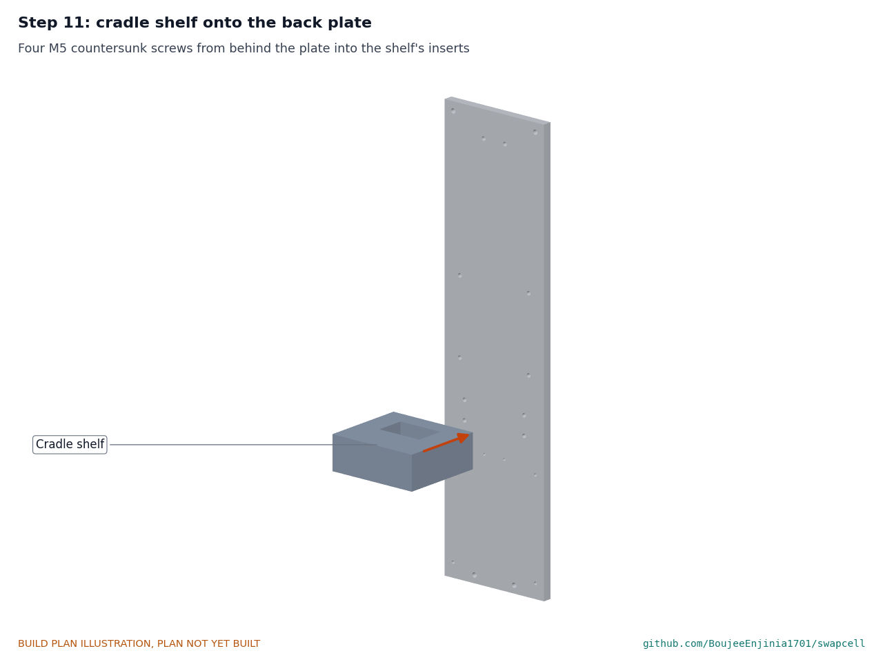
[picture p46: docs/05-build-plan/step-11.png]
Step 11


Four M5 countersunk screws from behind the plate into the shelf's inserts.

### Step 12: side guides onto the back plate

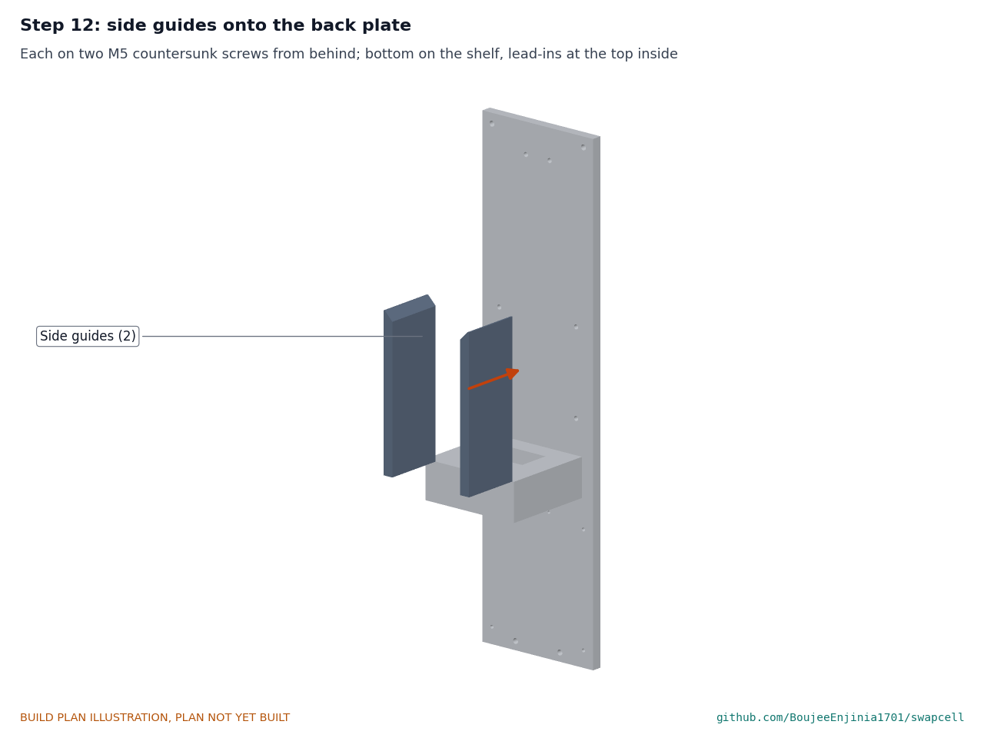
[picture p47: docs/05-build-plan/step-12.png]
Step 12


Each on two M5 countersunk screws from behind, bottom on the shelf, lead-ins at the top inside.

### Step 13: latch catch onto the back plate

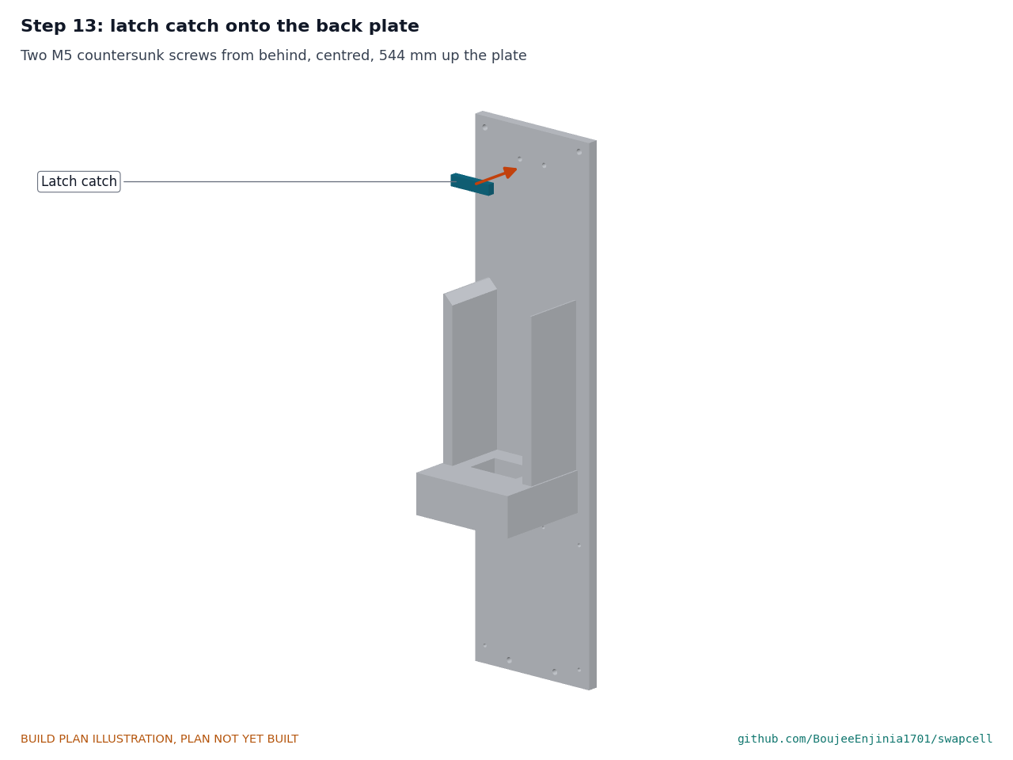
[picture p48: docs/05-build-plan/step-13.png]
Step 13


Two M5 countersunk screws from behind, centred, 544 mm up the plate, latching face down.

### Step 14: receptacle into the shelf

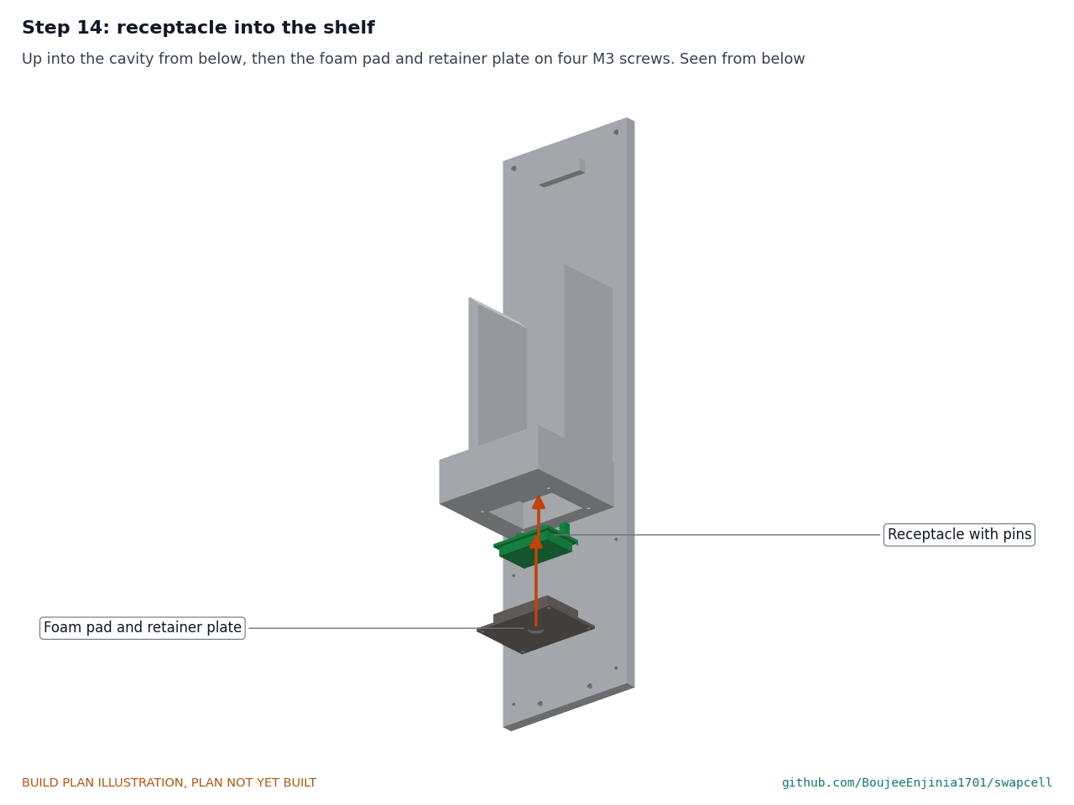
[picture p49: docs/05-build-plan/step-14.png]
Step 14


Seen from below. Pass the wires down through the retainer's grommet, push the receptacle up into the cavity with its key post at the back right, then the foam pad and the retainer plate on four M3 screws.

### Step 15: controller box, charger and straps

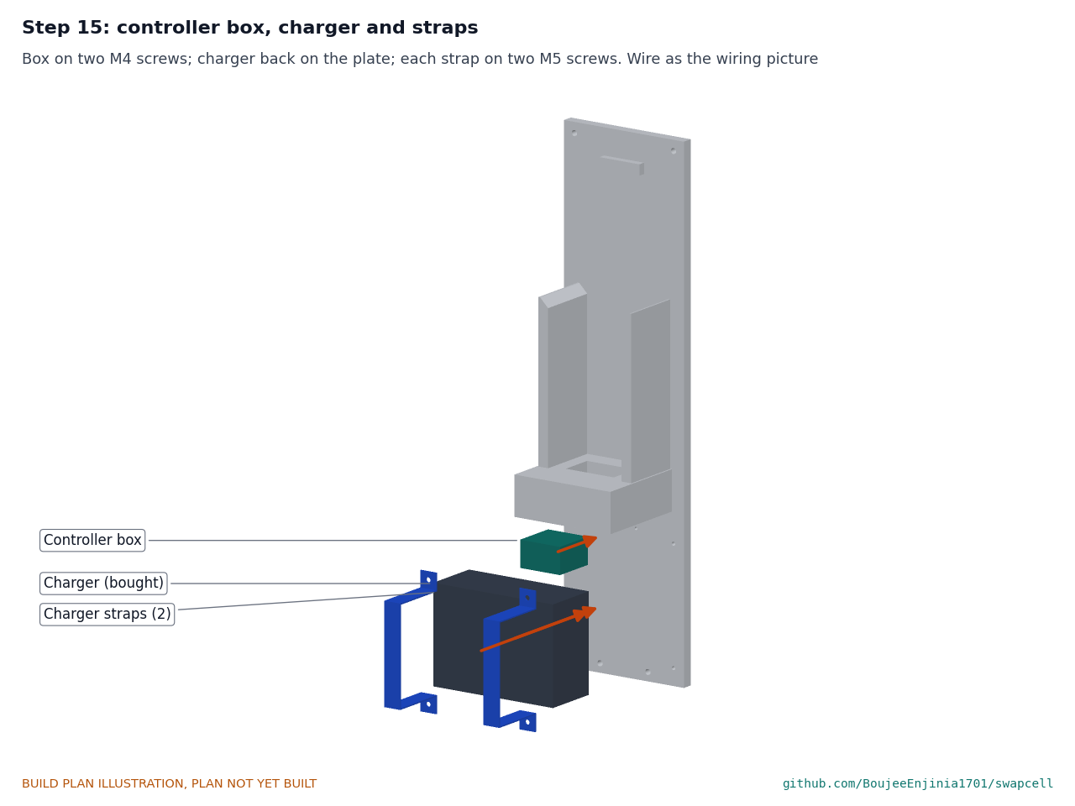
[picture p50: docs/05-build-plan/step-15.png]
Step 15


The controller box on two M4 screws; the charger with its back on the plate; each strap over it on two M5 screws. Wire the dock as Figure 12 with the charger unplugged.

### Step 16: dock onto the wall

Step 16

Four 6 mm screws into wall anchors in a non-combustible wall, the shelf top 0.8 to 1.2 m above the floor, away from exits. **Hold point:** safety stop S5.

### Step 17: pack into the dock

Step 17

Lower the pack, connector end down, between the guides. It drops onto the shelf, the plug finds the receptacle, and the pawl snaps out under the catch. To remove it, press the thumb button and lift. **Hold point:** safety stop S6.

## 5. First checks

These are the checks a TRL 4 test report would record; this plan only lists them. Requirement numbers are those of SWC-REQ-001.

*Table 2. First checks.*

| Check | Requirement | How | Pass when |
| --- | --- | --- | --- |
| Envelope | R6 | Calipers and a rule on the closed pack | Body 340 x 90 x 80, within +0 and -1.5; 400 mm or less overall (393 expected); no head proud of the back or sides |
| Mass | R5 | Weigh the finished pack | 3.5 kg or less (3.03 kg estimated) |
| Output dead until seated | R11, R13 | Pack out of the dock: meter across PACK+ and PACK-; then a coin across INTERLOCK and signal ground | 0 V in both cases |
| Wake on the coding resistor | R13 | Seat the pack in the dock with the controller off | The board wakes and reports the loop valid; output stays off until a heartbeat |
| Sleep current | R13 | Meter in series with the cell block negative, board asleep | 100 µA or less |
| Handshake and log | R12 | Dock controller on; read the pack's identity and export its log | Identity read; log exported as CSV |
| Charge | R4 | Dock charges the pack from about 3.5 V per cell, attended, inside the fireproof enclosure | 5 A, give or take 0.25 A, in constant current; charging stops at 54.6 V, give or take 0.2 V |
| Cold charge lockout | R11, R14 | Replace one thermistor with a resistor equal to its value at -1 °C | Allowed charge current reads zero; no charge current flows |
| Latch hold | R15 (class D) | Lift the seated pack by the handle without pressing the button; then press and lift | It stays put; with the button pressed it lifts out |
| Swap | R7 | Time a one-handed swap; push the pack in with a spring scale | 10 s or less; 50 N or less |
| Receptacle float | R10 | Move the receptacle by hand with the pack out | 3 mm each way, returns level |
| Lid seal | R8 | Look at the gasket line under a lamp with the lid on | Evenly squeezed, no gaps (the spray test comes later) |

## 6. Safety stops

Stop at each point. Carry on only when everything listed is true.

- **S1. Before the cells come into the workshop.** Cells new, from an authorized distributor, with a datasheet; each between 3.4 and 3.7 V and within 0.05 V of the others; no dents or damaged wraps. A fireproof enclosure ready (a steel cabinet or a purpose-made battery containment box) on a non-combustible surface, with a lithium-rated or Class D extinguisher and a bucket of sand within reach. Insulated tools only.
- **S2. Before the cell block goes into the tray.** Every group voltage measured and within 0.05 V; every strip weld pulled by hand and every fuse wire intact; the block wrapped in fish paper; the tray liner in place; the battery management board not yet connected.
- **S3. Before the balance connector goes on.** Each sense lead measured at the connector, in order, rising by 3.0 to 4.2 V per pin; connected in the order the board's maker gives; the main fuse still out.
- **S4. Before the lid closes.** Main fuse in; with no receptacle, PACK+ to PACK- reads 0 V; a coin across INTERLOCK and signal ground still reads 0 V; no wire pinched or near the flange screws; the pack still inside the fireproof enclosure.
- **S5. Before the charger is plugged in.** Dock on a non-combustible wall, away from exits, with a smoke alarm nearby; charger certified and undamaged, on an RCD-protected socket; receptacle polarity checked with a meter against the plug; the charger's output measured at 54.6 V with no pack in.
- **S6. First charge in the dock.** The pack has completed one attended charge inside the fireproof enclosure. Stay with it the whole time; check the cell temperature every 15 minutes; stop if any cell passes 45 °C or any group passes 4.2 V. Never charge below 0 °C, never bypass the board's protections, and never charge a pack that has been dropped, crushed or wetted.
- **S7. Handling.** The pack weighs about 3 kg: carry it by the handle, never by the lid. Move it between rooms in a rigid, non-conductive container with the plug covered.

## 7. Tools, skills and workspace

**Tools.** Box-and-pan folder taking 1.5 mm aluminium 400 mm wide (or a sheet-metal shop); bench drill; drills 2.5 to 16 mm and a step drill; 90 degree countersink and one to suit the rivet heads; taps M3, M4 and M5 with their drills; hacksaw and bandsaw or jigsaw for 12 mm plate; flat and needle files; deburring tool; scriber, square, steel rule and calipers; bench vice with soft jaws; hand rivet tool for 3.2 and 4 mm rivets; 3D printer with an enclosure that prints ASA and flame-retardant PC-ABS, with a bed of at least 250 x 250 mm and 200 mm tall (350 mm for a printed lid); heat-set insert tip for a soldering iron; capacitor or battery spot welder for nickel strip; soldering iron; crimpers for ferrules, contacts and 6 mm² lugs; insulated hand tools; multimeter; bench power supply with a current limit; spring scale to 100 N; stopwatch; scale to 5 kg.

**Skills.** Basic sheet metal and metalwork (marking out, folding, drilling, tapping, filing, riveting), 3D printing, crimping and soldering, and experience of building lithium-ion packs with spot-welded strip under supervision. The pack works at up to 54.6 V DC and can deliver hundreds of amperes into a short, so treat it as a hazard at every stage. No mains wiring is part of this build: the charger is a certified plug-in unit.

**Workspace.** A bench about 1.5 x 0.7 m with a metalwork corner kept apart from the battery area so chips cannot reach the cells; a ventilated place for the printer; the fireproof enclosure of S1 for every stage from the cell block on; a non-combustible wall for the dock.

**Personal protective equipment.** Safety glasses for cutting, drilling, spot welding and soldering; cut-resistant gloves for sheet and plate edges; hearing protection when sawing; no gloves near a turning drill; no rings, watches or metal bracelets when working on the cells.

## 8. Where the numbers come from

- Model and constructability checks: `cad/src/model.py` (`python cad/src/model.py --check`); STEP and STL exports in `cad/step/` and `cad/stl/`.
- Pictures: `cad/src/build_plan_media.py`, using `.kit/build_views.py`; written to `docs/05-build-plan/` and `cad/drawings/SWC-DWG-101` to `SWC-DWG-115`.
- General arrangement: `cad/drawings/SWC-DWG-002.pdf`, Rev P4.
- Calculations: `docs/04-calcs/01-sizing.md` (SWC-CAL-001 v0.4) and `docs/04-calcs/sizing.py`: mass (section 3), thermal (section 4), latch (section 6), cost (section 8).
- Bill of materials: `bom/bom.csv` and `bom/bom-notes.md`.
- Decisions: `docs/decisions/0003-design-for-construction.md` (SWC-DDR-003), with SWC-DDR-001 and SWC-DDR-002.
- Requirements: `docs/03-requirements.md` (SWC-REQ-001 v0.5). Interface: `docs/02-concept.md` (SWC-PRC-001 v0.5).

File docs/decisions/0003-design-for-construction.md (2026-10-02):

---
doc_id: SWC-DDR-003
title: SwapCell design for construction
project: SwapCell
doc_type: Design decision record
version: "0.2"
status: Draft
date: '2026-10-02'
author: Amish Chadha
license: CERN-OHL-S-2.0
revisions:
- version: "0.1"
  date: '2026-10-01'
  author: Amish Chadha
  change: Changes that make the concept physically buildable, with the reason for each; made under Amish's 2026-09-30 instruction to make the design physically buildable; open for his review
- version: "0.2"
  date: '2026-10-02'
  author: Amish Chadha
  change: "Accepted by Amish on 2026-10-02, including the recommendations for A1 to A4 (A3 changes the printed-lid decision for the prototype)"
---

# 0003: Design for construction

- **Date:** 2026-10-01
- **Status:** accepted. Amish, 2026-10-02: "i approve your recommendations for all 555 open decisions." This covers every change in Tables 1 and 2 and the recommendations for A1 to A4 in Table 3, which are now decided as recommended and recorded in the design decisions register (SWC-DEC-001). A3 changes the printed-lid decision of 2026-09-25 for the prototype.

## Context

On 2026-09-30 Amish asked for every repo to get an illustrated prototype build plan and wrote: "If you are realising that the design cannot be built as per concept - fix the design assumptions to match and be physically feasible as you draw the illustrations." The TRL 3 model of SwapCell (`cad/src/model.py` before this record) was a massing model: it showed what the pack and dock do and fixed the published interface, but most parts had no fixing, and some could not work as drawn. Checking it with build123d found the problems in Table 1. The worst was the latch: the catch on the dock sat 2 mm below the pawl instead of above it, so it could never stop the pack being lifted out, and the spring-loaded pawl had neither room to retract nor a release.

The changes keep what the product does and what the interface publishes: the 340 x 90 x 80 mm body, the 393 mm overall length, the connector position and pinout, the guide faces, the latch position (36 mm wide on the back face, 45 mm below the top end) and its class V1 proof load, the handle zone, the flush wake button, the cells, the BMS, the charger and the controller. Nothing here changes the pitch or the safety case. Every change is in `cad/src/model.py`, which now builds each component as it is made or bought, with its fixings, and runs 71 constructability checks (`python cad/src/model.py --check`): parts that must touch do touch, parts that must not touch are apart by at least the stated clearance, the pawl hooks 4 mm under the catch and clears it by 1 mm when retracted, and the body stays inside the envelope. All 71 pass.

## Decision

*Table 1. Changes made to the model, the BOM and the calculations.*

| # | Problem in the concept | Change made | Why this way |
| --- | --- | --- | --- |
| P1 | The dock catch sat 2 mm below the pawl, so it only stopped downward movement (the shelf's job) and never held the pack in; the pawl's outer face rubbed on the back plate. | The catch, now a separate 50 x 12 x 8 mm steel bar on two M5 screws, sits 1 mm above the pawl's top face and reaches 8 mm out from the plate, 2 mm clear of the pack. The pawl stands 6 mm proud (was 10), hooks 4 mm under the catch and is 4 mm clear of the plate. | A pawl must pass the catch on the way in and hook under it, as in any spring latch. The 4 mm engagement and the tooth size are those of the class V1 sizing in SWC-CAL-001, so the proof load result stands. |
| P2 | The spring-loaded pawl had no mechanism: to pass the catch it needed to retract about 10 mm, but the cells sat 7 mm behind the back wall; there was no release under the handle. | The pawl is a steel block that slides through a 37 x 25 mm slot in the back wall, in a folded 1.5 mm steel housing riveted inside the wall with six countersunk blind rivets (the latch doubler). A shoulder on the pawl rests on the wall as its out stop; two springs push it out. A steel release slider runs down the inside of the wall; its 45 degree ramp wedges against a matching ramp on the shoulder, so pressing the printed thumb button on top of the slider 5 mm pulls the pawl in 5 mm, 1 mm clear of the catch. A lead-in on the tooth lets the catch push the pawl in as the pack drops. The cell block moves 8 mm toward the lid to make room. | A wedge needs no pivots, pins or small parts and can be filed by hand. The housing doubles as the doubler that the latch sizing already assumed, with the same six 4 mm rivets. The thumb button sits just behind the grip, where a hand that lifts the pack presses it naturally, matching the "thumb release under the handle" of the precis and the renders. |
| P3 | The 3 mm lid sat on the 1.5 mm edges of the tray with no fixing and no gasket seat; screws cannot go into a 1.5 mm edge. | 8 mm flanges folded inward round the open front of the tray; eight M3 press-in nuts in the flanges; eight M3 countersunk screws through the lid; a 1 mm flat gasket between lid and flanges. The tray is 1 mm shallower (76 mm) so tray, gasket and lid still make exactly 80 mm. | Press-in nuts in folded flanges are the usual way to close a sheet-metal box; the flat gasket gives the sealing face R8 needs. The envelope is unchanged. |
| P4 | The plug shroud was drawn against the connector face with no fixing and no way for its wires into the pack. | Four M3 screws from inside the tray into heat-set inserts in the shroud; a 42 x 22 mm lead opening in the connector face, sealed with a bead of sealant; the contact holes go through the shroud so contacts are fitted from the top with their wires. | Screws from inside leave the connector face clean and can be reached with the lid off. |
| P5 | The carry handle had no fixing. | Two M5 screws from inside the tray up into heat-set inserts in the handle's legs. | Same reasoning as P4; nothing protrudes from the top end. |
| P6 | The cells floated in the tray; the cell holders in the BOM were not modelled. | Two printed holder frames, one near each end of the cells, with 26 pockets each; their back edges rest on the tray back wall, two M2.5 countersunk screws each from outside. The right frame is notched to clear the latch housing. | Frames that bear on the wall locate the 1.8 kg block in every direction; countersunk screws keep the back face flat. |
| P7 | The BMS board floated beside the cells. | Four 2 mm standoffs and M2.5 countersunk screws through the right side wall; the board is 2.5 mm clear of the cell ends. | Countersunk heads keep the guide face flat. |
| P8 | The receptacle was drawn inside the solid shelf (25,000 mm³ overlap) with no float, although R10 asks for ±3 mm. | The shelf has a 72 x 50 mm cavity under the plug pocket. The printed receptacle has a flange that the pocket's 6 mm ledge captures from above, with 3 mm to float each way; a 15 mm foam pad and a 3 mm aluminium retainer plate on four M3 screws hold it up. The key post moves to the receptacle and the pins are modelled with the INTERLOCK pin shortest. | A captured, sprung receptacle is the simplest floating mount. The foam also lets it tilt the 2 degrees of R10. |
| P9 | The side guides stood 10 mm in front of the back plate, fixed to nothing. | Guides run back to the plate (70 mm deep), two M5 countersunk screws each from behind into heat-set inserts; the 10 mm lead-in of the interface is now modelled. | Bolting to the plate carries the knocks of a careless swap. |
| P10 | The shelf, catch and plate were one fused solid with no fixings. | Shelf on four M5 countersunk screws from behind the plate into inserts; catch on two M5 countersunk screws. | Each part can be made and replaced on its own. |
| P11 | The controller box hung 10 mm off the plate and 35 mm past its edge. | It sits on the plate between the charger and the shelf, on two M4 screws. | Inside the plate, close to the receptacle wiring. |
| P12 | The charger had no fixing. | Two folded 20 x 1.5 mm aluminium straps over it, each on two M5 screws into tapped holes; the plate grows from 520 to 580 mm (bottom edge 170 mm below the dock datum, top edge 10 mm above the pack's top end) to carry the straps and the catch. | Works with any brick charger of about the same size, without drilling it. |

*Table 2. Knock-on changes.*

| Item | Change | Reason |
| --- | --- | --- |
| Mass | Pack 3.03 kg (was 2.85 kg) [SWC-CAL-001 v0.3, section 3]: latch housing, slider, button and springs 0.11 kg; pawl and handle from model volumes 0.13 kg (was 0.10); fixings 0.10 kg (was 0.08); tray flanges 0.03 kg. R5 (3.5 kg) is still met with 0.47 kg margin. Energy density 154 Wh/kg (was 164). | Parts added for construction. |
| Thermal | Heat capacity 2.29 kJ/K (was 2.26), time constant 33 min (was 32); hot spots unchanged at 51, 63 and 71 °C; enclosed derating current about 18.6 A (was 18.5). R3 stays met on paper. | Heavier tray. The cells no longer touch the back wall (P2); the lumped model's 0.10 K/W core-to-tray assumption is listed as proposed item A4. |
| Cost | BOM lines 1, 4 to 9 and 11 to 13 updated, lines 15 (latch housing, slider and springs), 16 (cell holder frames, moved from line 12) and 17 (dock mounting parts) added. Pack USD 436, dock USD 170, total USD 606 against the USD 700 value-engineering target (`budget_usd`, unchanged), USD 94 under. | Parts added for construction. |
| Drawings | SWC-DWG-002 Rev P3; making sketches SWC-DWG-101 to 115 added. | Follow the model. |
| Documents | SWC-CAL-001 v0.3, SWC-REQ-001 v0.5, SWC-PRC-001 v0.5: mass, cost, thermal and latch description updated. No requirement changed status. | Follow the model. |
| Interface | No published value changed. Two clarifications are proposed (A1, A2). | |

*Table 3. Proposed, then accepted by Amish as recommended on 2026-10-02.*

| # | Question | Options | Recommendation |
| --- | --- | --- | --- |
| A1 | The thumb button sits 3 to 19 mm behind the published handle zone (84 x 22 mm), so a receiver built to the letter of interface v0.3 could put structure over it. | (a) widen the handle zone in interface v0.4 to the full depth behind the handle (84 x 43 mm, from the zone's front edge to the back face); (b) move the release forward under the grip, which needs a lever. | (a): no change to the pack, one line in the interface. Accepted 2026-10-02. |
| A2 | The catch geometry that makes the latch work (latching face 1 mm above the pawl, reach 8 mm from a plate 10 mm behind the pack, 4 mm engagement, 1 mm clear when retracted) is not published, but every receiver needs it. | (a) add it to interface v0.4 with the pawl's 6 mm projection and 5 mm travel; (b) leave it to each receiver design. | (a), so vehicle receivers in PowerBox, CargoMule and others latch the same way. Accepted 2026-10-02. |
| A3 | A 90 x 340 mm lid needs a printer with a bed of at least 350 mm; Amish's 2026-09-25 decision was a printed lid. | (a) print it on a large-format printer; (b) cut it from 3 mm UL 94 V-0 polycarbonate sheet, same shape and holes. | (b) for the prototype: easier to source and flatter; the drawing allows either. Accepted 2026-10-02, changing the printed-lid decision of 2026-09-25 for the prototype. |
| A4 | Moving the cells 8 mm toward the lid (P2) leaves them clear of the back wall, so heat reaches the tray through the holder frames and air rather than through pads on the wall. The lumped thermal model keeps its 0.10 K/W core-to-tray assumption. | (a) keep the assumption and check it in the TRL 4 load test, relying on the PACK_LIMITS derating meanwhile; (b) add a thermal pad between the rear row of cells and the latch housing area now. | (a): the derating rule already holds cells under 60 °C whatever the path, and the test measures it. Accepted 2026-10-02, with the battery board's temperature sensor on the rear row of cells, now furthest from the tray. |

## Consequences

- `design_state: constructable` in `project.yaml`. The build plan SWC-BLD-001 shows every component and step in pictures generated from the model (`cad/src/build_plan_media.py`); open items are in the design decisions register SWC-DEC-001.
- Requirement status is unchanged: none not met, 2 at risk (R2, R9), 5 not verifiable at TRL 3, 8 met (four on paper only), and R16 under the value-engineering target (SWC-CAL-001 v0.3).
- The photoreal renders (`media/render-*.png`), `media/card.png` and `media/social-preview.png` still show the concept: six lid screws instead of eight, a 10 mm pawl, guides standing off the back plate, a shorter back plate and no charger straps. They need regenerating on Amish's Mac, where Blender is. The appearance model `cad/src/product_model.py` reads its sizes from the model and was not edited.
- With A1 and A2 accepted, the SwapCell interface is issued as v0.4 in SWC-PRC-001 (handle zone 84 x 43 mm; catch geometry published). With A3, the prototype lid is cut from 3 mm UL 94 V-0 polycarbonate sheet. With A4, the battery board's temperature sensor goes on the rear row of cells.
- TRL 4 remains on hold by Amish's instruction. Nothing was built or bought.

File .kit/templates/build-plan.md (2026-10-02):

---
doc_id: PRJ-BLD-001
title: Project prototype build plan
project: Project name
doc_type: Build plan
version: "0.1"
status: Draft
date: YYYY-MM-DD
author: Amish Chadha
license: CERN-OHL-S-2.0
revisions:
  - version: "0.1"
    date: YYYY-MM-DD
    author: Amish Chadha
    change: First build plan; design made constructable
---

# Project prototype build plan

**Plan, not yet built.** How to build the first proof-of-concept prototype, component by component. Building and testing to it is TRL 4 work. Decisions still to be made are kept in the design decisions register (`docs/06-design-decisions.md`), not here.

## 1. What you are building

Every component, pulled apart and numbered in build order

One short paragraph: what the prototype is, how many components, which are made and which are bought, and the main ways they are made.

## 2. What changed to make it buildable

| Component | The concept had | The buildable design has | Why |
| --- | --- | --- | --- |

## 3. Making the components

### 3.1 Component name

Making sketch

**What it is and what it is made from.**

**How to make it.**

1. Mark out ...
2. Cut ...

**How it fits the parts next to it.**

Close-up of the joint

**Check before moving on.**

## 4. Putting it together

### Step 1: ...

Step 1

## 5. First checks

| Check | Requirement | How | Pass when |
| --- | --- | --- | --- |

## 6. Safety stops

## 7. Tools, skills and workspace

## 8. Where the numbers come from

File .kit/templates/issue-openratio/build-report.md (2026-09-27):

---
name: Build report
about: Tell us what happened when you built, printed or tested part of this design
title: "Build report: "
labels: build-report
---

This is a research and educational prototype, not a medical device. It is a TRL 3 concept and is not released for fabrication. If you build any part of it, you do so at your own risk. Reports help everyone.

**What you built** (part, sub-assembly or test)

**Materials, tools and settings**

**What worked**

**What did not work, with photos or measurements if you have them**

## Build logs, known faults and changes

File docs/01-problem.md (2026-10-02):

---
doc_id: SWC-PRB-001
title: SwapCell problem statement
project: SwapCell
doc_type: Problem statement
version: "0.4"
status: Draft
date: '2026-10-02'
author: Amish Chadha
license: CERN-OHL-S-2.0
revisions:
- version: "0.1"
  date: '2026-09-24'
  author: Amish Chadha
  change: Initial scaffold
- version: "0.2"
  date: '2026-09-24'
  author: Amish Chadha
  change: Populate to TRL 2 (users, context, constraints, out of scope, prior work)
- version: "0.3"
  date: '2026-09-25'
  author: Amish Chadha
  change: TRL 3. Record Amish's 2026-09-25 decisions (SWC-DDR-001); dependents and needs updated for interface v0.3; budget scope
- version: "0.4"
  date: '2026-10-02'
  author: Amish Chadha
  change: "Partner order and LFP decision of 2026-10-02 recorded"
---

# SwapCell problem statement

Light electric vehicles run on batteries that only fit one brand, often one model, so a fleet with three vehicle types keeps three sets of packs and chargers, a flat pack cannot be swapped between vehicles, and a pack with one weak cell group is scrapped because nobody outside the brand can read its data or open it.

## The problem

E-bikes, e-scooters and cargo trikes mostly use 36 V or 48 V lithium-ion packs of 300 to 700 Wh. The cells inside are commodity 18650 or 21700 cells, but the housing, connector, mounting and battery management system (BMS) protocol are proprietary. The consequences are practical:

- **Fleets cannot share.** A delivery or rental operator with mixed vehicles must stock a separate pack and charger family for each, and cannot move charged packs to whichever vehicle is working.
- **Downtime is charge time.** Without a swappable pack, a vehicle stands still for 3 to 6 hours while it charges. Swapping takes seconds.
- **Packs die early and blind.** Without access to state-of-health (SoH) data, operators replace packs on a schedule or after failure. A pack that could be rebalanced, repaired or moved to a lighter duty is recycled instead.
- **Repair is locked out.** Independent repair shops cannot diagnose a pack whose BMS speaks a closed protocol, and a replacement from the original brand may cost more than the vehicle is worth.
- **Small builders have no target.** An open vehicle design (for example the SunSpoke e-bike kit or the WaterWalker assist in this portfolio) has no common pack to design around, so each project reinvents the battery.

SwapCell proposes an open, documented interface: one pack envelope, one blind-mate connector with a published pinout, one CAN message set, and a wall dock that charges and reads any conforming pack. The interface definition matters more than any single pack build, because other designs in the portfolio (PowerBox, SunSpoke, StepGen, WaterWalker, CargoMule, FieldCell and others) plan to use it. Their TRL 2 reviews raised three needs the v0.2 interface did not meet: waking a pack from a host that has no CAN or no wake supply, running loads while charging, and holding a pack in a vehicle under vibration. Amish approved adding all three on 2026-09-25; they are SwapCell interface v0.3 (SWC-PRC-001 v0.3, SWC-DDR-001).

## Users and context

| User | Need | Context |
| --- | --- | --- |
| Fleet operator (delivery, rental, campus or municipal) | Share packs and docks across vehicle types; swap in seconds; see which packs are ageing | Depot with a row of wall docks; 1 to 3 swaps per vehicle per day |
| Rural e-bike or cargo-trike user | Carry a spare pack; charge from a small solar system or a shared village dock; repair locally | Unreliable grid, long distances, heat and dust |
| Repair shop or community workshop | Read pack history, find a weak cell group, replace cells and return the pack to service | Workbench with a dock and a laptop |
| Open hardware builder | A pack and interface to design a vehicle or power product around | Makerspace or small workshop |
| Portfolio integrator (PowerBox, SunSpoke, StepGen, WaterWalker, CargoMule, FieldCell) | A stable mechanical envelope, pinout and message set to design to now, including wake without CAN, charge while discharging, and a vehicle latch rating | Paper design at TRL 2 and 3 |

## Constraints

- Garage-buildable prototype of one pack and one dock for about $700 USD (budget in `project.yaml`, kept by Amish on 2026-09-25), using commodity cells, an open-source BMS and off-the-shelf connectors and chargers. A SwapCell pack is priced once, in this repo, and excluded from the budgets of dependent kits.
- Lithium-ion cells are hazardous. Assembly needs a spot welder, cells from a reputable distributor (no recycled or unknown-grade cells for the reference pack), and a fire-safe space for building, charging and testing.
- The prototype uses a certified off-the-shelf mains charger. No custom mains-voltage electronics are built.
- Electrically compatible with common 48 V light-vehicle motor controllers (typical low-voltage cutoff 39 to 42 V, maximum input about 60 V).
- One-hand carry and swap, including by users with limited grip strength.
- Outdoor use: rain, dust, vibration and temperatures from about -10 °C to 45 °C during use.
- The interface documents must be publishable under the portfolio licenses, so the design cannot depend on a specification that users must buy or sign to read.

## Out of scope

- Automated or robotic swap stations, payment, booking and user accounts.
- A cloud fleet platform. The dock exports logs locally; any server is the operator's choice.
- Motor controllers and vehicle frames, beyond the mount that receives the pack.
- Fast charging above 1C and battery chemistries other than lithium-ion NMC or NCA cells in the reference pack (an LFP variant is not added now; a chemistry code and coding key are reserved for it, decided 2026-10-02).
- Certification testing. Relevant standards are listed as future targets, not claims.

## Prior work

- **Proprietary swapping networks.** Scooter swapping networks in Taiwan and India, and battery-sharing services in Europe, show that swapping works at scale, but each network uses its own pack and closed data.
- **Industry consortia.** Several large motorcycle makers formed a consortium to agree a common swappable pack for small electric motorcycles, and at least one maker sells a swappable pack family used across its own products. These are designed for 50 cc to 125 cc class vehicles, larger than the e-bike and cargo-trike packs targeted here, and their documents are not open.
- **EnergyBus (CAN in Automation profile 454).** An existing CANopen-based standard for light electric vehicle batteries, chargers and connectors. It is the closest precedent for the SwapCell message set. Its adoption in the e-bike market has been limited, and the specification is distributed through a membership organization.
- **E-bike integrated packs.** Mainstream e-bike drive systems use proprietary down-tube or rack packs with keyed connectors and closed BMS protocols.
- **DIY down-tube cases.** Generic "down-tube" pack cases for 13S packs are widely sold for hobby e-bikes and act as an informal mechanical standard, but they have no defined connector or data interface.
- **Open-source BMS projects.** Several open BMS designs for 12S to 18S packs with CAN exist and can serve as the starting point for the SwapCell BMS.
- **Regulation.** The EU Batteries Regulation (2023/1542) covers batteries for light means of transport and expects state-of-health information to be available from the BMS, which supports the SwapCell SoH logging requirement.

## Open questions

- Which user group to design with first: a delivery fleet, a rural e-bike cooperative, or a repair workshop? The portfolio picks co-design partners per area later; decided 2026-10-02: an urban cargo-bike or e-bike delivery fleet is approached first, with a repair workshop second.
- Message set: decided by Amish, 2026-09-25: an open SwapCell profile with an EnergyBus gateway study (SWC-DDR-001 item 4).

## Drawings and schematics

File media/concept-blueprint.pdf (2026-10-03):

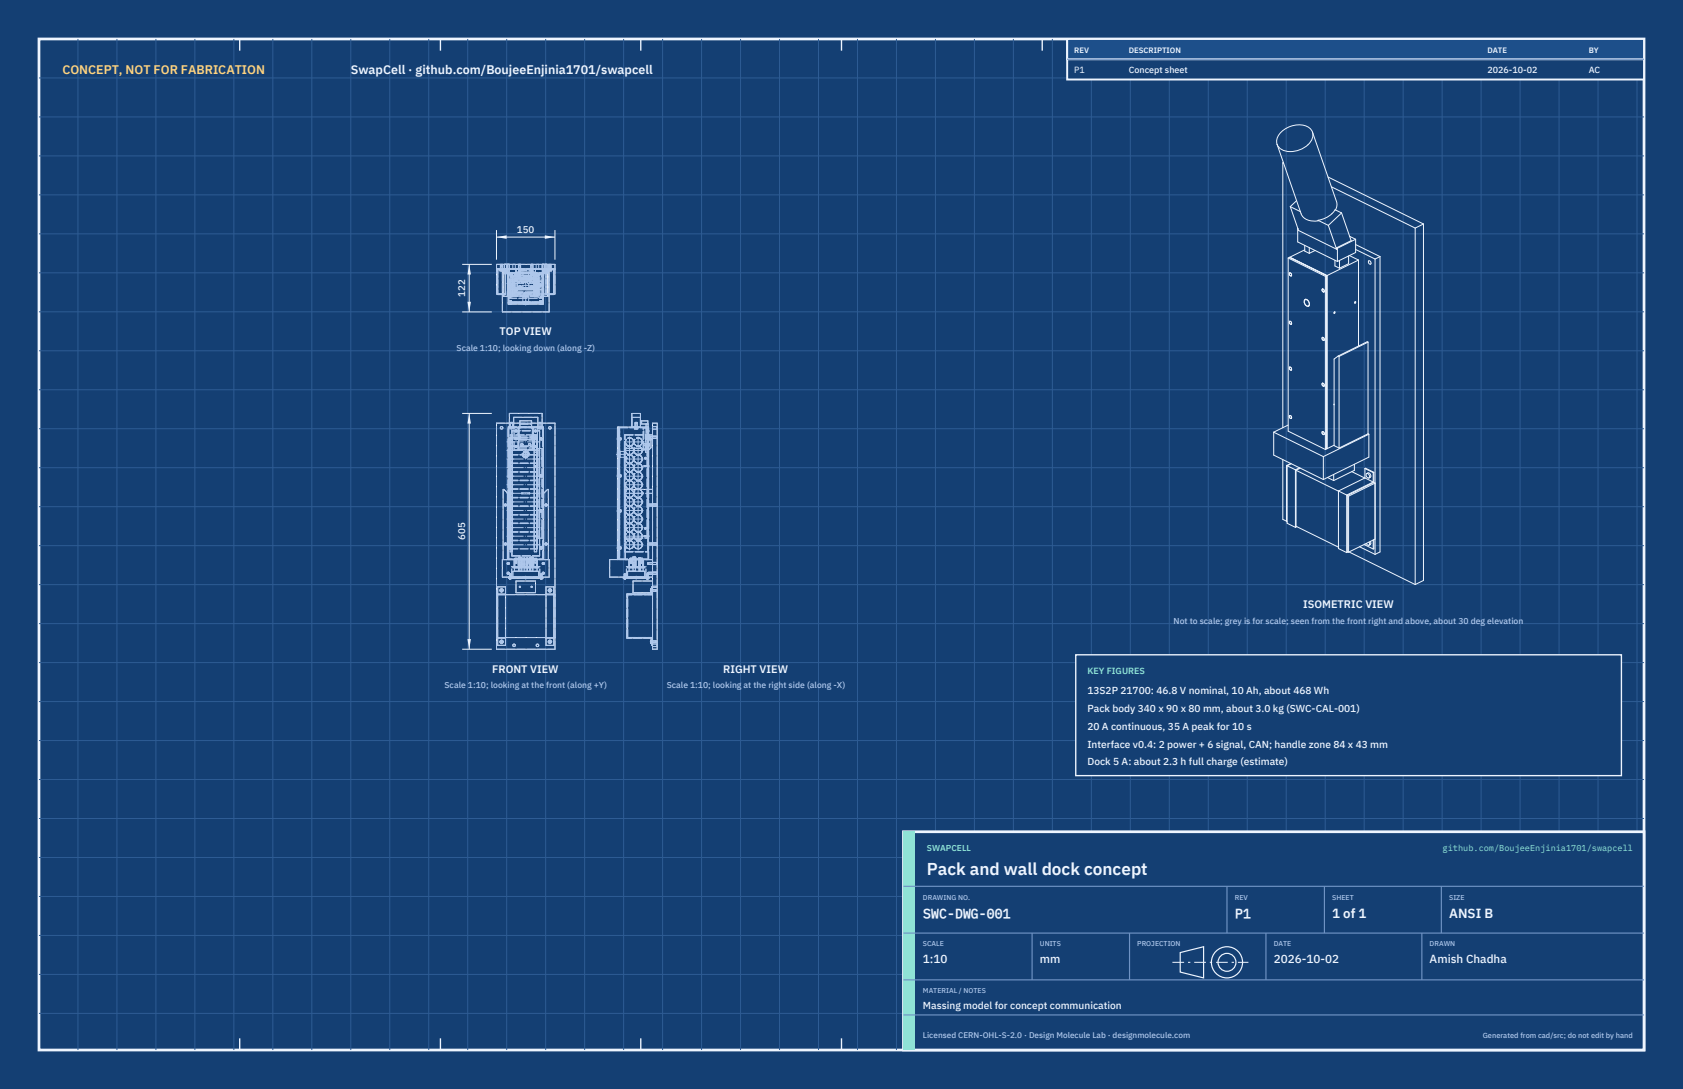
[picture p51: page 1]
CONCEPT, NOT FOR FABRICATION; SwapCell · github.com/BoujeeEnjinia1701/swapcell; FRONT VIEW; TOP VIEW; RIGHT VIEW; ISOMETRIC VIEW; REV; DESCRIPTION; DATE; Concept sheet; SWAPCELL; github.com/BoujeeEnjinia1701/swapcell; DRAWING NO. SWC-DWG-001; REV P1; SHEET 1 of 1; SIZE ANSI B; SCALE 1:10; UNITS mm; PROJECTION; DRAWN Amish Chadha; Licensed CERN-OHL-S-2.0 · Design Molecule Lab · designmolecule.com; Generated from cad/src; do not edit by hand

Scale 1:10; looking down (along -Z)

Not to scale; grey is for scale; seen from the front right and above, about 30 deg elevation

KEY FIGURES
13S2P 21700: 46.8 V nominal, 10 Ah, about 468 Wh
Pack body 340 x 90 x 80 mm, about 3.0 kg (SWC-CAL-001)
20 A continuous, 35 A peak for 10 s
Interface v0.4: 2 power + 6 signal, CAN; handle zone 84 x 43 mm
Dock 5 A: about 2.3 h full charge (estimate)

Scale 1:10; looking at the front (along +Y)

Scale 1:10; looking at the right side (along -X)

Pack and wall dock concept

MATERIAL / NOTES
Massing model for concept communication

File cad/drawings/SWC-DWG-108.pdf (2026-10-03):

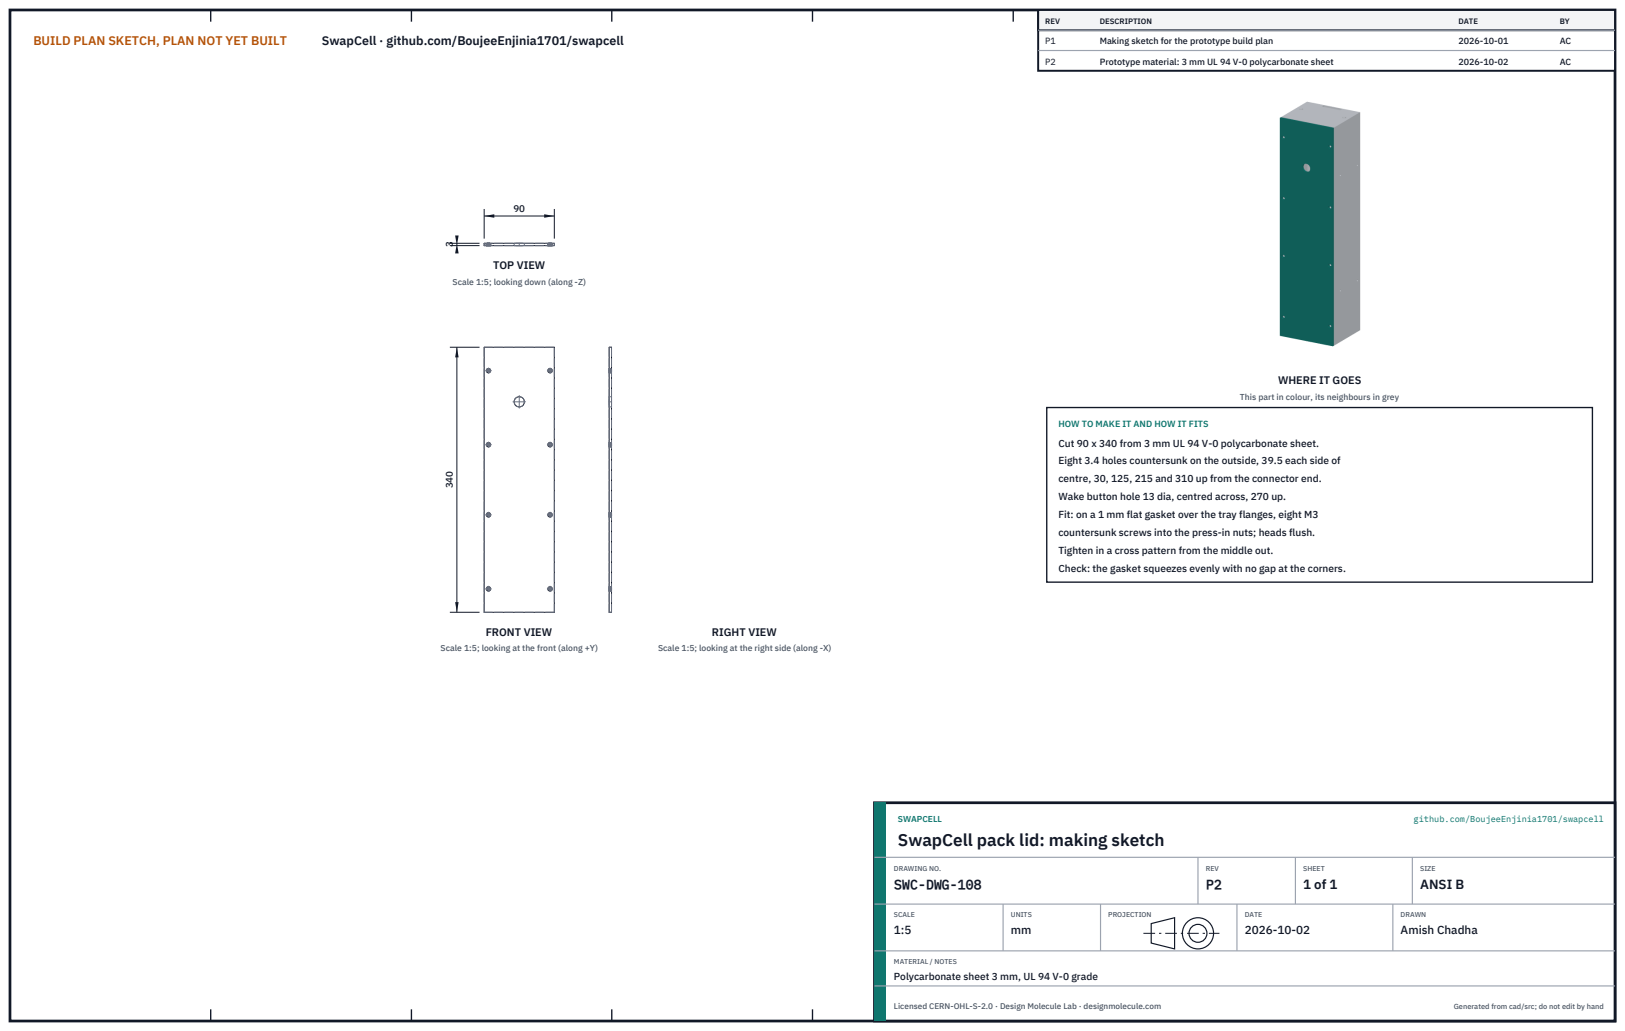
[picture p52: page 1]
BUILD PLAN SKETCH, PLAN NOT YET BUILT; SwapCell · github.com/BoujeeEnjinia1701/swapcell; FRONT VIEW; TOP VIEW; RIGHT VIEW; REV; DESCRIPTION; DATE; Making sketch for the prototype build plan; Prototype material: 3 mm UL 94 V-0 polycarbonate sheet; SWAPCELL; github.com/BoujeeEnjinia1701/swapcell; DRAWING NO. SWC-DWG-108; REV P2; SHEET 1 of 1; SIZE ANSI B; SCALE 1:5; UNITS mm; PROJECTION; DRAWN Amish Chadha; Licensed CERN-OHL-S-2.0 · Design Molecule Lab · designmolecule.com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

Scale 1:5; looking down (along -Z)

WHERE IT GOES

This part in colour, its neighbours in grey

HOW TO MAKE IT AND HOW IT FITS
Cut 90 x 340 from 3 mm UL 94 V-0 polycarbonate sheet.
Eight 3.4 holes countersunk on the outside, 39.5 each side of
centre, 30, 125, 215 and 310 up from the connector end.
Wake button hole 13 dia, centred across, 270 up.
Fit: on a 1 mm flat gasket over the tray flanges, eight M3
countersunk screws into the press-in nuts; heads flush.
Tighten in a cross pattern from the middle out.
Check: the gasket squeezes evenly with no gap at the corners.

Scale 1:5; looking at the front (along +Y)

Scale 1:5; looking at the right side (along -X)

SwapCell pack lid: making sketch

MATERIAL / NOTES
Polycarbonate sheet 3 mm, UL 94 V-0 grade

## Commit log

2026-09-24 Initial scaffold: standard open hardware layout, CERN-OHL-S v2 + MIT licenses
    Claude-Session: https://claude.ai/code/session_01XuhhSU4W6fYhgCfURbrkut
    [bom.csv]
2026-09-25 Adopt portfolio kit v1.3.0: session commands, scale figure, 3D viewer, flow diagrams
    Adds .claude/commands (/populate, /advance-trl3, /rein-in, /refresh-media)
    so every Claude Code session starts from the standard prompts, and extends
    concept media with a 1.75 m scale figure, an interactive glTF viewer and
    system or energy flow diagrams. TRL cap 3 unchanged.
    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
2026-09-25 Kit v1.3.1: renderer fixes from the TremorTrace pilot
    Context scale parts for small objects, cutaway exclusions, and text
    labels in flow diagrams.
    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
2026-09-25 Populate swapcell to a strong TRL 2 with concept media (batch 1)
    Problem, requirements and precis v0.2, massing model and concept media,
    indicative BOM, docs/REVIEW.md with decisions proposed and awaiting Amish.
    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
    [bom.csv]
2026-09-25 Advance swapcell to TRL 3 (batch 1)
    Decisions approved by Amish 2026-09-25 recorded in DDR-001. TRL 4 is on hold.
    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
    [bom.csv, results.csv, swapcell-assembly.step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]
2026-09-26 Accept all recommendations (DDR-002), switch footer to designmolecule.com, add README write-up with new inspiration point
    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
    [bom.csv, results.csv, swapcell-assembly.step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]
2026-09-27 Product appearance model and photoreal renders
    Adds cad/src/product_model.py (appearance model for renders only, all main
    dimensions from model.py) and Blender renders in media/render-*.png,
    captioned with the project, repository and viewing direction. README leads
    with the product render; trl stays 3.
    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
2026-10-01 Image quality pass: legible exploded views, flow diagrams and drawing sheets
    Kit 1.6.1 image layout: the parts list sits in its own column, number bubbles sit on visible parts and never overlap, small parts get a leader, pictures are cropped to the subject, flow labels keep numbers with their units, and sheet captions and the revision table no longer overprint. Concept images, blueprint and general arrangement sheet regenerated; repo-specific labels moved clear of other text and lines.
2026-10-02 Kit 1.7.0: constructable design, illustrated build plan and design decisions register
    The design is now constructable: every part can be made and fits its neighbours, with each change recorded in a Design for construction decision record (made under Amish's 2026-09-30 instruction; ope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
    FlexHand also credits Dr. Geeti Chadha as a contribut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
    [bom.csv, results.csv, swapcell-assembly.step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]
2026-10-02 Record Amish's approval of the open-decision recommendations
    Amish approved the recommendation on every open decision in the design decisions register ("i approve your recommendations for all 555 open decisions.", 2026-10-02). Each decision is moved to Decisio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
2026-10-03 Carry approved follow-ups into the design and redo photoreal renders
    Amish approved the follow-up actions from the open-decision sign-off ("APPROVED CHANGES, COMPLETE THESE", 2026-10-02), the design-for-construction change tables in ten repos, the last wave's open dec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
    [bom.csv, results.csv, swapcell-assembly.step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]

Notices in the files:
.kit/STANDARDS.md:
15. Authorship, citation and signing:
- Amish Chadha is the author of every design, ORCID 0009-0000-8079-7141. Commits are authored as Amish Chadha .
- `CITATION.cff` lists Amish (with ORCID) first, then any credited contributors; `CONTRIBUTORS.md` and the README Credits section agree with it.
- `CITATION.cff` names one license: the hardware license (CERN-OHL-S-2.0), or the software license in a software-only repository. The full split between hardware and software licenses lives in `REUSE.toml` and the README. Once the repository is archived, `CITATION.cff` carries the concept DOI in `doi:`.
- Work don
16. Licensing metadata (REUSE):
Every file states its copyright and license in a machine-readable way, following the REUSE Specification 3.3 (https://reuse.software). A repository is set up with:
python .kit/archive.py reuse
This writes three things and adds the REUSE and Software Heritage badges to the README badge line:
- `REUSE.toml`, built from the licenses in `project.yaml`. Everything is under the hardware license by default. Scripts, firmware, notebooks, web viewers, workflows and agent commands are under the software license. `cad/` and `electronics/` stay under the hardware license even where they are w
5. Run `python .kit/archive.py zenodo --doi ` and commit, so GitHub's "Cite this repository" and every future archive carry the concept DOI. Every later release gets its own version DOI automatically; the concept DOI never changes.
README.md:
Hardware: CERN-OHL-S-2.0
